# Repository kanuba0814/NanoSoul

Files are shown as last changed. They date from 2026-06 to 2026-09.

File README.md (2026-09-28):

# NanoSoul · ESP32-P4 桌面陪伴机器人

NanoSoul 是一台桌面陪伴机器人。它在本地检测人脸和环境，据此决定表情和动作；联网后可以进行语音对话。项目是团队参赛作品（2026 中国高校计算机大赛·人工智能创意赛），本仓库中的固件、测试上位机和文档由我提交。

当前实物是 **Waveshare ESP32-P4-WIFI6 开发板 + 现成模块 + 杜邦线**。

## 几个关键判断

- **实时决策不依赖云端。** 赛题要求主要功能运行在乐鑫芯片上，所以感知 → 决策 → 表情这条链全部在 ESP32-P4 本地完成：OV5647 → PPA 降采样 → ESP-DL 人脸检测 → 10 Hz、9 个状态的状态机。云端只负责深度对话，不进入决策环，因此断网时机器人照样能运转。
- **语音触发选能用的方案，而不是看起来高级的方案。** WakeNet9 和 MultiNet7 的模型加载和 AFE 管线都能跑，但在当前板载麦克风下口令检测不稳定。所以演示默认使用能量 VAD（检测到持续语音后才录音），再用 STT 文本判断是否包含唤醒词「小王」；神经网络方案保留为实验选项。
- **安全是硬需求，不是附加功能。** 电机堵转判定条件是 INA219 电流升高且编码器不动，触发后拉低 TB6612 的 STBY 急停；电机默认关闭，只有显式使能后才会驱动。
- **只有一块开发板，所以尽量把验证做在板外。** 共享脚本必须能在没有开发板的机器上运行；状态机、运动仲裁、堵转判定等逻辑都有板外自检（`soul_sim`、`arbiter`、`stall_sim` 等），上板后再用 SELFTEST 模式逐项确认。

## 验证状态

| 状态 | 内容 |
|---|---|
| ✅ 实物验证 | 本地人脸检测约 8 fps；480×640 屏幕动画表情约 30 fps；断网运行本地状态机；录音 → STT → LLM → TTS → 播放全链路（2026-07-08 打通，120 s 稳定性测试无 panic / WDT / reset）；WebSocket 上位机与测试模式 |
| 🟡 代码完成，只通过板外自检 | 三轮全向运动原语、堵转保护闭环、轮速闭环与里程计（校准记录尚未填写）；IMU、环境光组件需接线后实测 |
| ⬜ 未完成 | 外壳打印装配（目前只完成 SolidWorks 初步建模）、工具调用、OTA |

完整的功能清单和每一项的状态见 [`docs/00_成品全景与技术框架.md`](docs/00_成品全景与技术框架.md)。

## 开发方式

开发过程与 Claude Code 协作完成，约定写在 [`CLAUDE.md`](CLAUDE.md)：优先复用乐鑫官方组件，现成没有的由 AI 产出、人工复核；commit 前固件必须通过 `idf.py build`；AI 给出的接线、电平和上电顺序全部由人复核。

## 目录

```text
main/                 程序入口和板级驱动（电机、编码器、INA219）
components/           视觉、状态机（soul）、表情、运动、语音、联网、自检等组件
esp_emote_gen_player/ 乐鑫表情播放器（vendored）
spiffs_image/         表情资源包
sdcard_template/      SD 卡配置示例，不含真实密钥
tools/testhost/       浏览器测试上位机与诊断工具
enclosure/            SolidWorks 外壳源文件与导出
docs/                 系统说明、接口协议、引脚表和测试记录
```

## 编译与烧录

开发环境：ESP-IDF v5.5.2，目标芯片 ESP32-P4。

```bash
source $IDF_PATH/export.sh
idf.py set-target esp32p4
idf.py build
idf.py -p /dev/ttyACM0 flash monitor   # 需要连接开发板
```

SD 卡配置和上板自检见 [`docs/10_上板验证_SD配置与烧录.md`](docs/10_上板验证_SD配置与烧录.md)。复制 `sdcard_template/nanosoul/config.example.json` 到 SD 卡 `/nanosoul/config.json`，填写 Wi-Fi 和模型服务配置；真实密码和 API Key 不进仓库。

## 运行模式

- `FACE`：默认模式，运行表情、视觉、状态机、语音、联网和上位机服务。
- `SELFTEST`：循环运行整机自检，输出 JSON 结果。
- `TEST`：在完整运行时之上增加传感值注入、电机测试和串口协议；上电时 IO48 接地即可进入。浏览器上位机为 [`tools/testhost/index.html`](tools/testhost/index.html)，协议见 [`docs/13_测试模式与上位机_v1.md`](docs/13_测试模式与上位机_v1.md)。

## 硬件接线

开发板由 USB 供电，电池经 XL6009 升压后单独给电机供电，两路电源必须共地；电机干线走母排并星形接地，避免电机一转电机电源就被拉低到 1.3 V。引脚见 [`docs/BOARD_MAPPING.md`](docs/BOARD_MAPPING.md)，接线图见 [`docs/应急方案_无PCB/`](docs/应急方案_无PCB/)。

## 分支与标签

| 分支 / 标签 | 内容 |
|---|---|
| `main` | 当前整机固件 |
| `v1.0-submission` | 赛前提交时的验证版本 |
| `test` | 完整测试固件：全量组件、testhost 与工具链 |
| `test-host` | 测试上位机与公开版文档整理 |
| `soul-app` | 交互里程碑 M1–M8：自主行为、堵转保护、微动作 |
| `feat-p4-hw-baseline-from-testP4` | 从测试板迁移 P4 硬件基线的最早版本 |

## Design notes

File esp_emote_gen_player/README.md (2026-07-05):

# ESP Emote Gen Player

<p align="center">
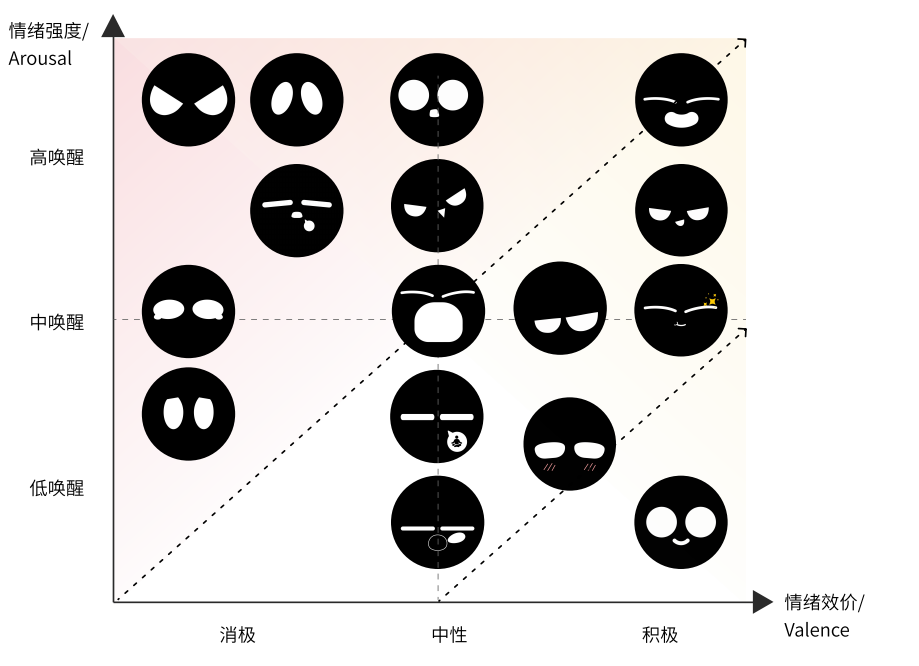
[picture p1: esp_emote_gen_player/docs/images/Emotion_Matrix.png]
情绪矩阵 — 效价 × 唤醒度与表情资产分类
  
</p>

**Emotion design specification · 表情设计规范**

The matrix above is the **current taxonomy** for mapping emotional states (valence × arousal) to emote asset categories. Authoring, naming, and export should follow the official guidelines in the PDFs below (Simplified Chinese).

上图情绪矩阵为当前 **效价 × 唤醒度** 与表情资产类别的对应关系；制作、命名与导出请遵循下列 PDF 规范。

| Document |
| -------- |
| [表情动效系统规范文档.pdf](https://dl.espressif.com/AE/%E8%A1%A8%E6%83%85%E5%8A%A8%E6%95%88%E7%B3%BB%E7%BB%9F%E8%A7%84%E8%8C%83%E6%96%87%E6%A1%A3.pdf) |
| [表情设计规范.pdf](https://dl.espressif.com/AE/%E8%A1%A8%E6%83%85%E8%AE%BE%E8%AE%A1%E8%A7%84%E8%8C%83.pdf) |

**Languages / 语言:** [中文](#中文) · [English](#english)

---

## 中文

在设备上挂载 **打包工具导出的二进制资源包**，驱动 **`gfx_anim`** 播放（片段规划、立即切换与当前片段播完后再交接）。

页面顶部的 **情绪矩阵** 与 **两份规范 PDF** 定义分类与制作约束；导出资源时请与之对齐。

### 打包工具（主机端）：ESP Emote GFX Packer NEXT

> 浏览器端编辑工程，**导出 `*.bin`** 后烧录到设备；与目标屏的 **分辨率 / 画布** 一致即可。

**[ESP Emote GFX Packer NEXT (dev)](https://emote-gfx-gen-tool-dev.pages.dev/)**

#### 1. 屏幕设置

配置目标 **宽 / 高**（像素）、必要时 **矩形**画布与 **背景色** 并应用，使其与实际运行的显示屏一致。

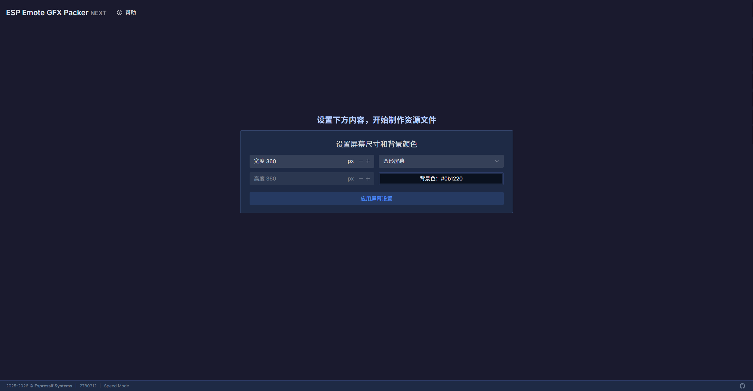
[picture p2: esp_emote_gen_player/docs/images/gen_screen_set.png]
ESP Emote GFX Packer NEXT — 分辨率与背景。


#### 2. 载入源动画

导入 **GIF**（或其它编辑器支持的来源）；按需调整时间轴与布局，细节见应用内 **Help**。

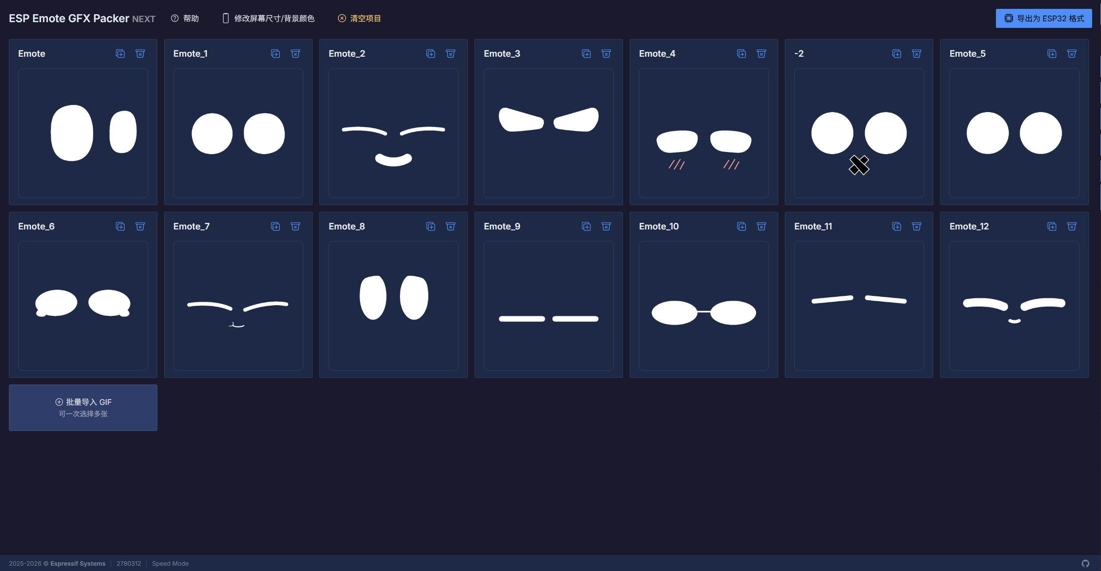
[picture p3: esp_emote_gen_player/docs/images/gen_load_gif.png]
ESP Emote GFX Packer NEXT — 将 GIF 载入工程。


#### 3. 导出

使用打包工具的 **导出 / 下载** 得到二进制；导出尺寸随编辑器中的 **屏幕设置**，源图层会 **自动缩放** 以适配画布。挂载后由 **本组件** 解析包内资源。

**`test_apps` 预编译示例包：** [`emote_assets.bin`](https://dl.espressif.com/AE/emote_assets.bin)

### 示例素材

> **GIF / Lottie** 等源文件合集，可导入上述打包工具再导出设备端包；由 **乐鑫 ESP 开源** 提供。

[**Emote Pack.zip**](https://dl.espressif.com/AE/Emote%20Pack.zip)

### 用法

将本仓库以本地路径加入工程依赖，初始化后挂载分区或路径上的资源包并切换动画：

```yaml
# idf_component.yml
dependencies:
  esp_emote_gen_player:
    path: ../path/to/esp_emote_gen_player
```

```c
#include "emote_gen_player.h"

emote_gen_player_handle_t player = emote_gen_player_init(&cfg);
// …

emote_gen_player_data_t data = {
    .type = EMOTE_GEN_PLAYER_SOURCE_PARTITION,
    .source.partition_label = "emote_gen",
    .flags.mmap_enable = 1,
};

ESP_ERROR_CHECK(emote_gen_player_mount_assets(player, &data));
ESP_ERROR_CHECK(emote_gen_player_anim_now_name(player, "idle"));
```

### 功能说明与测试

- 加载设备端由打包工具生成的 **二进制资源包**；挂载动画资源并接入 **`gfx_anim`** 的片段规划。
- **`emote_gen_player_init` / `deinit`**：gfx 运行时、单显示器、内部动画对象。
- **`emote_gen_player_mount_assets`**：从 **分区** 或 **文件系统路径** 加载资源包（可选 mmap）。
- **动画切换**
  - **`emote_gen_player_anim_now` / `_name`**：立即切到目标片段。
  - **`emote_gen_player_anim_fade` / `_name`**：先让当前片段规划播完（`gfx_anim_play_left_to_tail`），再切换 — **请勿在持有渲染锁的 gfx 触摸定时器回调里直接调用**；应放到其它任务中延迟执行（见 `test_apps`）。
- **本仓库 `test_apps/`**：独立 `idf.py` 工程（板级初始化、触摸安全的动画切换）。详见 **`test_apps/README.md`**。

---

## English

On device, **mounts packer-produced binary emote packs** and drives **`gfx_anim`** (segment plans, immediate switch vs. handoff after the current plan).

The **emotion matrix** and **two specification PDFs** at the top define taxonomy and authoring rules (Simplified Chinese); align exports with them.

### Pack tool (host): ESP Emote GFX Packer NEXT

> Author in the browser, **export `*.bin`**, then flash. Match the editor **canvas / resolution** to your target display.

**[ESP Emote GFX Packer NEXT (dev)](https://emote-gfx-gen-tool-dev.pages.dev/)**

#### 1. Screen setup

Configure **width / height** (px), optional **rectangular** canvas, and **background color**, then apply.

ESP Emote GFX Packer NEXT — screen size and background.

#### 2. Load source animation

Import **GIF** (or other supported sources). Adjust timing and layout; see in-app **Help** for details.

ESP Emote GFX Packer NEXT — load GIF into the project.

#### 3. Export

Use **Export / Download** to produce the binary. Export follows the **screen size** in the editor; layers are **rescaled** to fit. **This component** parses the mounted pack.

**Prebuilt sample for `test_apps`:** [`emote_assets.bin`](https://dl.espressif.com/AE/emote_assets.bin)

### Sample sources

> **GIF / Lottie** sources bundled for import into the packer above; **ESP open-source** from Espressif.

[**Emote Pack.zip**](https://dl.espressif.com/AE/Emote%20Pack.zip)

### Usage

Add this component via `idf_component.yml`, then mount a partition or filesystem path and switch clips:

```yaml
# idf_component.yml
dependencies:
  esp_emote_gen_player:
    path: ../path/to/esp_emote_gen_player
```

```c
#include "emote_gen_player.h"

emote_gen_player_handle_t player = emote_gen_player_init(&cfg);
// …

emote_gen_player_data_t data = {
    .type = EMOTE_GEN_PLAYER_SOURCE_PARTITION,
    .source.partition_label = "emote_gen",
    .flags.mmap_enable = 1,
};

ESP_ERROR_CHECK(emote_gen_player_mount_assets(player, &data));
ESP_ERROR_CHECK(emote_gen_player_anim_now_name(player, "idle"));
```

### What it does and tests

- Loads the packer-produced **binary asset pack**; wires **`gfx_anim`** segment plans.
- **`emote_gen_player_init` / `deinit`**: gfx runtime, one display, internal animation object.
- **`emote_gen_player_mount_assets`**: **partition** or **filesystem path** (optional mmap).
- **Animation switching**
  - **`emote_gen_player_anim_now` / `_name`**: cut to the target clip immediately.
  - **`emote_gen_player_anim_fade` / `_name`**: drain the current plan (`gfx_anim_play_left_to_tail`), then switch — **do not call from the gfx touch timer while the render lock is held**; defer to another task (see `test_apps`).
- **This repo — `test_apps/`**: standalone `idf.py` project. See **`test_apps/README.md`**.

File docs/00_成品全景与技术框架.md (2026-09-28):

# NanoSoul 成品全景与技术框架

> 本文汇总当前样机的功能、系统组成、实测结果和待完成事项，各专项以对应文档为准。
> 状态更新：**2026-07-26**。正式提交基线为 `v1.0-submission`；当前 `main` 另含 VAD 语音触发调整。

---

## 1. 最终成品定义

### 1.1 一句话定位（引自宪法 01）

> NanoSoul 是一台基于 ESP32-P4 的桌面陪伴机器人。它在本地检测人脸和环境状态，据此调整表情与运动；联网后通过云端服务完成语音识别、对话和语音合成。

赛题要求主要功能代码运行在乐鑫芯片上。NanoSoul 的视觉处理、状态判断和运动控制都在 ESP32-P4 上运行，云端服务不参与实时运动判断。断网演示用于验证这条本地处理链路。

### 1.2 成品功能全清单（含当前状态）

状态图例：✅ 已上板实测 · 🟡 已实现、待实测/待配置 · 📐 设计就绪、未实现 · ⬜ 待做

| 域 | 功能 | 技术落点 | 状态 |
|---|---|---|---|
| **感知** | 人脸检测（存在/位置/大小/正脸分） | OV5647 MIPI-CSI → PPA 降采样 300×480 → ESP-DL `HumanFaceDetect`（MSRMNP s8），实测 **8fps** | ✅ |
| | 距离代理 + 凝视判定 | bbox `area_ratio` 当距离、鼻眼关键点算 `frontal_score` | ✅ |
| | 碰撞 / 被抬起 / 倾斜 | QMI8658 软件检测（`components/imu`：敲击/双击/抬起/放下/倾斜），抬起→SOUL_LIFTED 反射停轮 | 🟡 组件就绪，待接线实测（imu_probe 自检） |
| | 环境光（暗光→睡觉） | BH1750 @I²C1 0x23（`components/light`，滞回→DARK/BRIGHT→SOUL_DOZE） | 🟡 组件就绪，待接线实测（light_read 自检） |
| | 电机电流（堵转判定输入） | INA219 @I²C1 0x40（`drv_ina219` 已有，TESTPANEL 已读通） | 🟡 |
| | 主人电脑状态（第二路在场/注意力源） | 上位机 `pc_state` 上报（09 v1.1）→ soul 注意力融合（12 §3.5，专注勿扰/挂机邀玩/锁屏预期） | 🟡（设备消费端已实现 fusion_sim 自检；采集端 PC 状态上报待做） |
| **决策** | soul 状态机（9 态，10Hz，全本地） | `components/soul`：IDLE/ENGAGE/APPROACH/RETREAT/GAZED/LISTEN/THINK/SPEAK/FAULT | ✅（`soul_sim` 自检 PASS） |
| | 主动陪伴行为：远了靠近、近了退后、朝脸转向、被盯久了害羞退避 | `soul_eval()`：area 阈值 + `wz=-0.8·cx` 居中 + gaze_hold 触发 GAZED | ✅ 逻辑实测，待接轮整机场测 |
| | 断网降级 | 感知→决策→表情/运动全链不依赖云 | ✅（bring-up 即断网跑通） |
| | 电机堵转急停（硬需求） | 电流高 + 编码器不动 → `motors_enable(false)` + FAULT，3 次试探恢复（`app_sense` stall FSM） | 🟡 闭环代码就绪（stall_sim 自检），待接轮实测 |
| **表达** | 动画表情脸（5 情绪：o/sad/sleep/think/waiting） | `esp_emote_gen_player`，640×480@30fps，90° 旋转刷 ST7701（480×640 竖屏） | ✅ |
| | 情绪↔状态映射 + 覆盖接口 | soul `apply_emotion()` / `soul_emotion_override()` | ✅ |
| | 对话字幕条（tip） | `face_set_tip()` | ✅ |
| | debug HUD（6 行遥测叠层，~2Hz） | `components/hud`，钉在 emote 画布上 | ✅ |
| | happy 表情 | 素材待做（07 P3） | ⬜ |
| **运动** | 三轮全向逆运动学（vx,vy,wz→三轮 duty） | `motion_ik()`，轮角 0°/120°/240°，饱和归一保航向 | ✅（`motion_ik` 自检 PASS） |
| | 实际驱动轮子 + 运动原语 | `motion.enabled` 默认 false 只算不驱动；意图仲裁器（6 源租约）+ 原语库（nudge/scan/spin/wiggle…）已实现 | 🟡 代码就绪（arbiter/prim_sim 自检），待接线（M1 IN 占 IO24/25 需挪脚） |
| | 编码器测速/里程 | PCNT ×4 解码，`ENC_COUNTS_PER_REV=28`（电机轴口径） | 🟡（TESTPANEL 自检固件实测过） |
| **语音对话** | 语音触发 | 默认能量 VAD：检测到持续语音后录音，再由 STT 文本门确认是否包含“小王”；MultiNet/WakeNet 保留为实验选项 | ✅ VAD 展示链与 120s 稳定性已验证；两套神经网络口令检测在当前条件下尚未稳定（2026-07-24） |
| | 录音→STT→LLM→TTS→播放 | `voice_task`：≤8s 录音尾静裁剪 → **seed-asr-2.0 单流 WSS 直连**（`volc_asr.c`）→ plan chat → seed-tts-2.0 HTTP → ES8311 播放；**全双工**（`WORK_MODE_BOTH`），播放期不读麦防回授 | ✅ **2026-07-08 实板全链打通**（说话→识别→回答→出声） |
| | 云端深度对话（三协议） | `llm_chat()`：Anthropic / OpenAI / **volc**（Agent Plan 端点 `/api/plan/v3` 或按量 `/api/v3`），SD 卡配 key；PC 侧 `tools/testhost/talk_probe.py` 可全链调参 | ✅ plan chat 实板已通 |
| | 文字问答（免语音） | 上位机 `ask` 命令 → `dialog_ask()` → 回复上字幕条 | 🟡 |
| **联网** | C6 WiFi6（esp_hosted/SDIO）、SNTP、mDNS `nanosoul.local` | `components/netlink` | 🟡（待 SD 配置实测） |
| **上位机** | WebSocket 接口：1Hz 全量 state + 即时 event + JPEG 快照 + 9 条命令 | `components/companion`，`ws://nanosoul.local/ws?token=…`，LAN only，协议冻结于 09 | ✅（`ws_loopback` PASS） |
| **供电保护** | 双电源共地（USB 逻辑 + 电池升压电机）、地母排星接 | 无 PCB 版实物方案（应急方案文档） | ✅ 实物验证 |
| **机械外壳** | 史莱姆形外壳（Ø160×h93，前脸 20° 后仰嵌屏，三全向轮 120° 布置一后两前） | `enclosure/`（SolidWorks 2024 手绘 + STL/3mf 导出） | 📐 初步建模，未打印装配 |
| **工具调用** | 本地工具（运动/表情/传感）+ 局域网 Home Assistant REST | 宪法 §4.5 混合方案 | ⬜ |

---

## 2. 系统技术框架

### 2.1 总框图

```
                         ┌─────────────── 云端（仅深度对话，不进决策环）───────────────┐
                         │  chat: Anthropic /v1/messages ←→ OpenAI /v1/chat/completions │
                         │  STT: /v1/audio/transcriptions   TTS: /v1/audio/speech       │
                         └────────────────────────△─────────────────────────────────────┘
                                                  │ HTTPS (esp_crt_bundle)
┌── 上位机 (PC/LAN) ──┐                ┌──────────┴──────────────  ESP32-P4 ─────────────────┐
│  WS 客户端           │◄── ws://…/ws ──┤ companion │ llm │ netlink ── C6 WiFi6 (esp_hosted)   │
│  state/event/snapshot│                │           │     │                                    │
└─────────────────────┘                │  ┌────────┴─────┴──────────────────────────┐        │
                                       │  │        telemetry（快照 + 事件总线）        │        │
                                       │  └──△───────△────────△───────△─────────△───┘        │
   OV5647 ─ MIPI-CSI ─ camera ─► vision ──►│ soul ──►│ motion ─► TB6612×2 ─► 3×N20+全向轮      │
   （800×1280）  (PPA→300×480)  (ESP-DL 8fps)│ 10Hz    │  IK      （PCNT 编码器×3 回采）         │
                                       │    └──────►│ face ──► emote player ─► ST7701 480×640 │
   ES8311 麦/喇叭 ◄── audio ◄── voice ──┘  (表情+tip+HUD)         (640×480@30fps, 90°旋转)     │
   SD 卡(config.json) ── storage_sd     QMI8658/BH1750/INA219 @I²C1（传感三件套，接入中）       │
└──────────────────────────────────────────────────────────────────────────────────────────┘
```

### 2.2 硬件：当前实物

固件对着无 PCB 模块版编写，接线真值见 CLAUDE.md 固件节与 BOARD_MAPPING.md。

| 载体 | 状态 | 要点 |
|---|---|---|
| **无 PCB 杜邦版** | ✅ 在用 | 现成模块 + 杜邦线；双电源（电脑 USB 供开发板、1S 电池→XL6009 升 5.9V 只带电机）**必须共地**；红/蓝母排干线 + 星地（锚点 XL6009 OUT−），防「电机一转 VM 塌到 1.3V」复发。细节见 `docs/应急方案_无PCB/` |

### 2.3 计算平台与板载资源

Waveshare **ESP32-P4-WIFI6**（v1.3 硅版实测）：16MB flash（QIO）/ 32MB PSRAM（200MHz，XIP）/ ESP32-C6 协处理（WiFi6，SDIO esp_hosted）。板载外设（引脚宏见 `components/bsp/bsp_pins.h`）：

- **屏**：ST7701S 480×640 竖屏，MIPI-DSI 1-lane@700Mbps。
- **相机**：OV5647，MIPI-CSI，SCCB@I²C0 0x36。⚠️ CSI 与 DSI 共用 MIPI DPHY 电源轨，靠 `cmake/patch_esp_video_ldo.cmake` 把 esp_video 补丁到 **LDO_VO3@2500mV**，否则相机不上电。
- **音频**：ES8311 codec（I²C0 0x18，I2S0）+ NS4150B 功放（PA_EN=IO53），16kHz/16bit/mono 全双工。
- **SD**：**SDSPI 模式**（CLK=IO43/MOSI=IO44/MISO=IO39/CS=IO42），LDO_VO4 供 IO 轨。
- **I²C0**（IO7/IO8）：板载三客户（codec/触摸/相机 SCCB），`board_i2c0` 组件统一建总线；**I²C1**（IO20/IO21，100kHz）：外接传感三件套。

### 2.4 固件架构（18 组件 + main）

ESP-IDF v5.5.2，`idf.py set-target esp32p4`。分层：

| 层 | 组件 | 职责一句话 |
|---|---|---|
| 地基 | `telemetry` | 全局遥测快照（mutex 保护）+ esp_event 事件总线，所有组件的汇聚点 |
| | `storage_sd` | SDSPI 挂卡 + `/sdcard/nanosoul/config.json` 字段级 overlay 配置（缺卡用内建默认） |
| | `bsp` / `board_i2c0` | 板载固定引脚宏 / I²C0 总线单例 |
| | `selftest` | 自检注册表 + 循环跑批，每项一行 JSON 到串口（19 项，见 §4） |
| 感知 | `camera` | esp_video(V4L2) 采 800×1280 RGB565 → PPA 全 FOV 降采样 300×480 → 帧回调；硬件 JPEG 快照 |
| | `vision` | ESP-DL 人脸检测（C++），产出 `tel_face_t{present,cx,cy,area_ratio,frontal_score}` |
| 决策 | `soul` | 10Hz 状态机：人脸观测 + 外部刺激（语音会话/故障）→ motion intent + face 情绪 |
| 表达 | `face` | emote 播放器薄封装：点屏、90° 旋转 flush、挂 `emote_gen` 分区、切换队列 |
| | `hud` | 遥测 6 行叠层（SOUL/FACE/MOT/ENC/NET/FPS），让没接的外设参数也可见 |
| 运动 | `motion` | 全向 IK + 输出闸：disabled 只算 + 发遥测；enabled 才经回调驱 `drv_motor` |
| 语音 | `audio` / `voice` | ES8311 录放 / wake→录音→STT→chat→TTS→播 全流水线（半双工） |
| 云 | `llm` / `dialog` | 双协议 chat + STT/TTS 客户端 / 单轮对话编排（voice 与上位机 ask 共用） |
| 网络 | `netlink` / `companion` | C6 WiFi + SNTP + mDNS / WS 服务（state/event/命令，token 鉴权） |
| 板级驱动 | `main/drv_motor·drv_encoder·drv_ina219` | TB6612（LEDC 20kHz）/ PCNT 正交 / INA219——无 PCB 外接件，TESTPANEL 实例化 |

（`display` 组件只服务 legacy TESTPANEL 的 LVGL 面板；FACE 模式的脸走 emote gfx 链，**不经 LVGL**。`esp_emote_gen_player/` 是 vendored 乐鑫官方播放器，`face` 是它的薄执行层。）

**三种启动模式**（编译期 Kconfig `NANOSOUL_MODE` 单选）：

- **FACE**（默认，产品/演示）：完整运行时——脸+HUD+视觉+soul+motion+网络+云+语音+companion。
- **SELFTEST**（首次上板/烤机）：同一套运行时 + 每 5s 一轮 19 项自检循环。
- **TESTPANEL**（legacy）：LVGL 三电机点检面板，与整机解耦。

**任务与核分配**：

| 任务 | 组件 | 核 | 优先级 | 周期 |
|---|---|---|---|---|
| gfx 渲染（emote 内部） | face | 1 | 7 | 30fps |
| `stream_task` 相机采集 | camera | 1 | 5 | V4L2 循环 |
| `detect_task` 人脸推理 | vision | 0 | 4 | 尽力（实测 8fps） |
| `soul_task` 决策 | soul | 0 | 5 | 10Hz |
| `voice_task` 语音会话 | voice | 0 | 5 | 事件驱动 |
| `switch_worker` 表情切换 | face | 0 | 6 | 队列 |
| `dialog_task` | dialog | 0 | 4 | 队列(4) |
| `hud_task` | hud | 0 | 4 | 500ms |
| `push_task` WS 心跳 | companion | 0 | 3 | 1Hz |

### 2.5 云端与上位机

- **chat 双协议**（`chat.provider` 选）：Anthropic（`x-api-key` + `anthropic-version: 2023-06-01`，system 顶层字段）或 OpenAI 兼容（Bearer，system 进 messages[0]）。非流式短回复，`max_tokens` 默认 512，TLS 用内置证书 bundle，超时 20s。
- **STT/TTS**：OpenAI 兼容 `/v1/audio/transcriptions`（multipart WAV）与 `/v1/audio/speech`（收 WAV→最近邻重采样到 16kHz）。三套端点可指不同 provider，各配各的 key。
- **上位机 WS**（协议冻结 = 09）：`state` 1Hz 全量 / `event` 即时（soul_transition·face_present/lost·gazed·wake·llm_reply·fault·selftest_item）/ binary JPEG 快照；命令 `ask·set_emotion·teleop·get_snapshot·estop·clear_fault·config_reload·set_overlay·selftest`，一律回 `ack{id,ok,err}`。未知 type 必须忽略（前向兼容铁律）。

---

## 3. 技术配合：数据流与契约

### 3.1 本地感知→决策→输出链路（断网可用）

```
OV5647 → camera(core1) —PPA 300×480→ vision(core0, ESP-DL) → tel_face_t
    → soul_task 10Hz: soul_eval()
        ├─ motion_set_intent(vx,vy,wz) → IK → duty[3] → 遥测（enabled 时才驱 TB6612）
        ├─ apply_emotion() → face_set_emotion() → emote 播放器 → 屏
        └─ telemetry_set_soul() + SOUL_TRANSITION 事件
    → hud 2Hz / companion 1Hz 从同一遥测快照对外可视化
```

决策优先级（`soul_eval`）：FAULT > 语音会话（LISTEN/THINK/SPEAK，不动）> GAZED 回避（vx=−0.5，1.5s 窗）> 无脸 IDLE（可选 idle_scan）> 有脸按 `area_ratio` 分档：>near_hi→RETREAT、<near_lo→APPROACH、之间→ENGAGE；ENGAGE 里 `frontal>0.7` 累计 ≥`gaze_hold_ms`→GAZED。所有有脸态叠加 `wz=−0.8·cx` 朝脸转向。阈值全部走 SD 配置 `behavior{}`，可现场调。

### 3.2 语音会话流水线（全双工硬件，会话半双工时序）

能量 VAD 唤醒（1s 预卷环把触发词并入录音；或上位机 `voice_trigger`）→ `soul_notify_wake()`（LISTEN + tip「(听)」）→ 录音 ≤8s/尾静 800ms（静音阈 rms&lt;350）→ THINK → seed-asr WSS（空文本=误唤醒，**静默丢弃**不打扰）→ chat → 回复上字幕条 + `LLM_REPLY` 事件 → SPEAK → TTS → 播放（PA 拉高，期间不读麦防回授）→ 回感知闭环。失败路径有声（fail tone 两下行音）+ tip 文案；断网不发请求直接兜底。

### 3.3 事件总线与遥测快照

单一事实源两条路：**连续量**走 `tel_snapshot_t` 快照（生产者 setter 写 / 消费者 `telemetry_get()` 原子读）；**离散事件**走 esp_event（`ns_event_id_t`）。事件当前唯一订阅者是 `companion`（转 WS `event` 帧）：

| 事件 | 发布者 | 含义 |
|---|---|---|
| `NS_EVT_SOUL_TRANSITION` / `NS_EVT_GAZED` | soul | 状态跳变 / 凝视触发 |
| `NS_EVT_FACE_PRESENT` / `NS_EVT_FACE_LOST` | vision | 人脸出现/消失边沿 |
| `NS_EVT_WAKE` / `NS_EVT_FAULT` | soul（voice/外部触发） | 唤醒 / 故障（含 estop） |
| `NS_EVT_LLM_REPLY` | voice / dialog | 云回复文本（≤160B） |
| `NS_EVT_SELFTEST_ITEM` | selftest | 单项自检结果 |

### 3.4 配置系统（密钥纪律）

`/sdcard/nanosoul/config.json`（模板 `sdcard_template/`，**真实密钥只在卡上、永不进仓库**），字段级 overlay 内建默认、缺卡可跑：
`wifi{ssid,password}` · `chat{provider,base_url,api_key,model,max_tokens,system_prompt}` · `stt{…}` · `tts{…,voice}` · `behavior{near_lo=0.04,near_hi=0.18,frontal_thresh=0.70,gaze_hold_ms=1500,idle_scan}` · `motion{enabled=false,max_duty_pct=40}` · `companion{enabled=true,token}` · `debug{overlay=true,log_level}`。上位机 `config_reload` 命令可热重载。

### 3.5 存储布局与资源管线

16MB flash，A/B 双 OTA（`partitions.csv`）：`ota_0/ota_1` 各 5MB · `emote_gen` 1.5MB（表情包）· `human_face_det` 1MB（人脸模型，label 名是组件硬性要求）· `model` 3MB（ESP-SR 语音模型：mn7_cn + wn9_nihaomiaoban_tts2，label 名是 esp-sr CMake 自动烧录的硬性要求）· `storage` FAT。
表情资产：`spiffs_image/*.bin`（5 情绪各一包，共 ~991KB）—构建时 `tools/emote_repack.py` 合成 `nanosoul_emote.bin` 随 `idf.py flash` 烧入 `emote_gen`，运行时 mmap 挂载。

### 3.6 内存纪律（bring-up 实证）

`SPIRAM_MALLOC_ALWAYSINTERNAL=4096`：≥4KB 分配走 PSRAM（emote 绘制缓冲、语音 utterance、TTS 累积均在 PSRAM），保住 256KB 内部 SRAM；esp_hosted mempool 也必须进 PSRAM（`ESP_HOSTED_MEMPOOL_PREFER_SPIRAM=y`），否则开机断言循环。PPA 输出缓冲按 cache line（128B）对齐，否则丢帧。

---

## 4. 实测基线（2026-07-05 上板 bring-up，v1.3 硅版）

自检矩阵（SELFTEST 模式，19 项）：**13 PASS · 4 SKIP · 1 FAIL**

- ✅ PASS 含全部核心链路：`sd_mount/config_parse/psram/partition_layout`、`emote_mount/emote_render/hud_draw`、`i2c0_probe/camera_stream/face_detect`、`motion_ik/soul_sim`、`codec_playback`、`ws_loopback`。
- ⏭ SKIP ×4：`wifi_connect/sntp/llm_ping`（SD 未配 WiFi/key）+ `wakenet_load`（MANUAL，本版能量 VAD）。
- ❌ FAIL ×1：`mic_record`——ES8311 ADC 静音（录音路径此前标注为板上未验证项）。**→ 已于 2026-07-08 语音链上板收尾打通（`ec3af47`）：mic 录音正常、说话→seed-asr→云 LLM→seed-tts→出声全链实测、对话可演示；此 07-05 FAIL 已消解，自检计数待重跑刷新。**

关键实测数字：相机 800×1280 采集 → 人脸检测 **8fps**；emote 渲染 640×480@**30fps**；断网状态本地闭环（看到人→表情/意图响应）完整跑通。bring-up 踩坑与修复（hosted mempool、LDO、PPA 对齐、HUD mask_buf 等）已固化进 `sdkconfig.defaults` 与代码，复现细节见 10 篇附录与 commit `baf909d`。

---

## 5. 差距清单：从成品倒推

### A. 固件收尾（对着现有无 PCB 硬件就能做）

> 交互行为的完整设计（场景库/情绪引擎/运动原语/仲裁架构）= **12 篇**。**I0–I2 已全部代码落地并板外 build 通过**（8 个里程碑 commit，纯逻辑自检 6 项恒绿：arbiter/expr/fusion/imu/prim/stall_sim；SELFTEST 自检项从 19 增至 28）。以下为剩余：

1. ~~**修 `mic_record` FAIL**（ES8311 ADC 静音）——语音链路唯一断点，最高优先。~~ **已解（2026-07-08 `ec3af47`）**：mic 录音打通，说话→seed-asr→云 LLM→seed-tts→播放全链上板实测、对话可演示。
2. ~~交互 I0+I1~~ **已落地（待上板实测）**：motion 意图仲裁器（已修 teleop 被 soul 覆写）、表情规则引擎、短期记忆、PC 状态融合；传感三件套组件就绪（QMI8658 敲击/抬起/倾斜、BH1750 暗光→DOZE、FT6x36 触摸单读者）——接线后 SELFTEST 的 `imu_probe/light_read/touch_probe` 应转 PASS。
3. ~~接轮 I2~~ **代码就绪（待接轮真机验证，由 Captain 执行）**：运动原语库、自主行为（零位移约束）、微动作、**堵转过流保护闭环**均已实现且 build 通过；上板前先挪 M1 IN1/IN2 出 IO24/25（USB-JTAG 冲突）→ SD 配 `motion.enabled=true`。
4. **语音触发后续工作（2026-07-24）**：当前默认使用能量 VAD（RMS>220 持续 160ms）启动录音，再由 STT 文本门确认“小王”。提示音、STT→LLM→TTS 和续聊已完成实物测试，120s 内未出现 panic、WDT 或 reset。MultiNet7-cn 和 WakeNet9 的模型加载及 AFE 管线可以运行，但口令检测在当前板载麦克风和模型配置下尚未达到稳定展示要求，因此保留为实验选项。
5. happy/blink 表情素材 + PPA 硬旋转优化（07 P3、12 I3）；IMU 片上事件引擎（当前软件检测，P1）。

### B. 硬件落地

1. **外壳**：SolidWorks 初步建模已完成，尚未打印装配；电池方案待统一（当前无 PCB 版为 1S 软包）。

### C. 比赛交付

1. 断网演示脚本 + 现场 fallback。
2. 上位机 PC 客户端：WS 协议真值见 09（已冻结、companion 已实现）；含 **PC 状态采集上报**（机器人的第二路感知，09 v1.1 `pc_state`）。
3. 工具调用（本地工具 + HA REST demo）、OTA、报名材料（宪法 §4.5）。

---

## 6. 文档地图与阅读顺序

| 篇 | 定位 | 状态 |
|---|---|---|
| **00（本文）** | 成品全景 + 技术框架 + 差距，docs 入口 | 2026-07-05 基线 |
| 01 项目宪法 | 不可动摇的核心决策：赛题、定位、原则、反面清单、答辩话术 | 有效（§4.2 已按去悬崖/QMI8658 修订） |
| 02 硬件规格附录：驱动可用性 | 外设官方驱动/组件可用性 | 有效 |
| 06 IMU 选型查证 | QMI8658 顶替 ICM-42688-P 的证据链 + 下单料号（QMI8658A） | 当前 IMU 真值 |
| 07 表情子系统 | emote 播放器接入的执行计划 | **已执行完毕**（P0–P2 落地，P3 开放） |
| 08 整机程序总体计划 | Phase 0–F 的架构与验收计划 | **已全部执行完毕**；as-built 架构见本文 §2–§3 |
| 09 上位机接口协议 v1 | WS 协议真值（冻结） | 已实现（companion），与实现一致 |
| 10 上板验证 | 持板者操作手册：SD 配置、烧录、读自检 | 有效；含 bring-up 实测记录 |
| 12 整机交互设计 | 行为真值源：智能感七原则、15 场景库、情绪引擎、运动原语、意图仲裁、I0–I3 分期 | v1，2026-07-05（设计态，待落地） |
| BOARD_MAPPING | 引脚真值源（模块版） | 有效 |
| 应急方案_无PCB/ | 当前实物接线真值（母排/星地/双电源） | 有效，与固件一致 |

**阅读顺序建议**：新读者 00 → 01 → 10（想上手跑）或 00 → BOARD_MAPPING（想动硬件）或 00 §2–§3 → 代码（想动固件）。

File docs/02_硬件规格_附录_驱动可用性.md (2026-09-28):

# 02 硬件规格 附录：外设官方驱动/组件可用性

> 本附录追加到《02_硬件规格_P0.3》。**硬件选型本身不变**（已确认），本附录只标注每个外设"是否有乐鑫官方现成驱动/组件可直接用"。

## 1. 外设驱动可用性映射

| 外设 | 接口 | 官方现成件 | 状态 | 固件策略 |
|---|---|---|---|---|
| OV5647 摄像头 | MIPI-CSI | **esp_video + esp_cam_sensor**（自动检测 OV5647，自带 ISP） | ✓ 官方 | 改配置即用；CSI 供电需 LDO 2500mV |
| MIPI-DSI 屏 | MIPI-DSI | **esp_lvgl_port**（`lvgl_port_add_disp_dsi`，P4 PPA） | ✓ 官方 | 直接用；PPA 实验性，留软渲染回退 |
| BH1750 环境光 | I²C1 | **`espressif/bh1750`** 组件 | ✓ 官方 | 直接用 |
| 磁编码器 | GPIO/PCNT | **PCNT `rotary_encoder`** 示例 | ✓ 官方 | 移植，三路 PCNT 正交解码 |
| N20 电机 | PWM | **MCPWM `mcpwm_bdc_speed_control`**（带 PID） | ✓ 官方 | 单电机示例 → 改写三电机 |
| TB6612FNG | GPIO+PWM | 无需专用驱动 | — | LEDC/MCPWM + 方向 GPIO |
| INMP441 / 板载麦 | I²S | **ESP-SR AFE**（采集 + AEC/VAD） | ✓ 官方 | feed/fetch 流水线对接 |
| ES8311 codec | I²S | **esp_codec_dev** | ✓ 官方 | 直接用 |
| ESP32-C6（WiFi6） | SDIO | **esp_hosted**（板载已预刷） | ✓ 官方 | 按文档配；配网两芯手动适配 |
| **QMI8658 IMU**（已换型，原 ICM-42688-P 方案废） | SPI / I²C | **SensorLib**（社区最全，含片上 Tap/WoM 事件引擎）、`waveshare/qmi8658`（官方 registry，原始数据） | ✓ 现成 | 直接用（选型证据链见 06）；换型原因之一 = ICM-42688 无官方 SPI 驱动 |
| ~~ITR20001 悬崖~~ | — | — | **已砍**（本版无悬崖） | 本版无悬崖传感器，IMU 兜底 lift/碰撞 |
| MT3608 / DW01+8205A / SS34 | 模拟电源 | — | — | 纯硬件，无固件 |

**小结（随 QMI8658 换型与去悬崖更新）**：外设几乎全部有现成件——IMU 换 QMI8658 后用 SensorLib/官方 registry 组件，悬崖已砍；不需要自写底层驱动。

## 2. 采购与硅版注意（更新）

- **优先采购 ESP32-P4 v3.x 硅版**：v3.x 修复了 ISP/MSPI 等若干问题（如 MSPI 上电唤醒 Load access fault、secure boot 校验异常），规避 MIPI-CSI 调试坑。
- **ESP-IDF 用 v5.4 / v5.5 稳定分支**（开发前回乐鑫赛题指引确认推荐版本）。
- **CSI 调试**：若 OV5647 偶发崩溃（如 0x102），开 `CONFIG_CAM_CTLR_MIPI_CSI_ISR_CACHE_SAFE` 等 IRAM 安全选项。
- ~~待确认项 Q1/Q2/Q3~~ **已解**（2026-07-05）：板 = Waveshare ESP32-P4-WIFI6，实到货 **v1.3 硅版**且整机 bring-up 已通过（docs/10 §6，CSI 靠 `ISR_CACHE_SAFE` + LDO_VO3@2500mV 补丁稳定）；板载麦经 ES8311（录音路径 `mic_record` 自检 FAIL 待查）。

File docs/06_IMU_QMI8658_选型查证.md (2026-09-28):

# 06 IMU 选型查证：QMI8658(C) 顶替 ICM-42688-P

> 背景：原计划 ICM-42688-P，实际到货是 **QMI8658**（紫色 GY 模块，丝印 QMI8658A / QMI8658C，引脚 VCC/GND/SCL/SDA/XDA/XCL/ADO/INT）。本文是对它能否替代的查证记录，供大家下单/接线前对一遍。
>
> 真值源说明：引脚分配以 [`BOARD_MAPPING.md`](BOARD_MAPPING.md) 为准；规格以 **QST 官方 QMI8658C Datasheet Rev A（文档号 13-52-27，2022-06-20）** 为准。本文不复述 datasheet 全文，只摘对决策有用的部分。

## 选型结论

> **下单(JLC SMT)注意（2026-06-30）**：嘉立创 SMT 库里 **QMI8658C(`C2842151`) 已停产/邮寄**，下单改同族 **QMI8658A(`C3021082`，现货 39k、可自动贴装)**。同 LGA-14、**脚位与 4 线 SPI 接法完全一致**（A 版 datasheet 13-52-25 Table 3 + Fig.4「4-Wire SPI」核过：1=SDO 4=INT1 5=VDDIO 6/7=GND 8=VDD 12=CS 13=SCL/SPC 14=SDA/SDI，2/3/9/10/11 SPI 下可悬空）、驱动同（SensorLib/Waveshare 同支持 A/C）→ **板与固件不动，仅 BOM 料号换**。本文余下规格按 C 版写，A 版同族同适用。

**QMI8658C 可以替代 ICM-42688-P 用在 ESP32-P4 上做本项目的 IMU**。它是 6 轴、支持 SPI 与 I²C、3.3V 可直供、有 INT1/INT2 两路中断，且**片上自带 Tap / Any-Motion / Wake-on-Motion 事件引擎**，碰撞、抬起、被搬动这几个事件可直接出中断，不必全靠固件算原始数据。

- **碰撞检测** → 片上 Tap（敲击）引擎，或 Any-Motion。
- **抬起 / 被搬动** → Any-Motion / Wake-on-Motion 引擎出中断。
- **电机堵转振动辅助** → 没有专用引擎（ICM 也没有），固件读高 ODR 原始数据做能量/FFT 阈值。这条两颗芯片一样，不影响选型。

代价：噪声比 ICM-42688-P 高（陀螺约 5 倍、加速度约 2 倍），陀螺量程上限只有 ±1024 dps，6 轴最大 ODR 7.17 kHz（ICM 是 32 kHz）。**这些差距对"撞了没 / 抬了没 / 振动超阈没"这种事件判定毫无影响**——我们不做姿态积分导航，用不上 ICM 的低噪声。结合驱动生态（见下），QMI8658 在本用途上反而更省事。

> 这一条同时更新了 [`02_硬件规格_附录_驱动可用性.md`](02_硬件规格_附录_驱动可用性.md) 第 18 行对 IMU 的判断：IMU 这项从「无官方驱动、需自研」改善为「有 Espressif 官方 registry 组件 + 成熟社区库」。

## 关键规格表

| 项目 | QMI8658C | ICM-42688-P | 出处 |
|---|---|---|---|
| 轴数 | 3 加速度 + 3 陀螺（6 轴，各 16-bit） | 同 | DS §1.3 Fig.2 |
| 加速度量程 | ±2 / ±4 / ±8 / ±16 g | 同 | DS Table 7 |
| 陀螺量程 | ±16 … **±1024 dps**（上限 1024） | ±2000 dps | DS Table 8 |
| 加速度最大 ODR | 仅加速度 1000 Hz；6DOF **7174.4 Hz** | 32 kHz | DS Table 9 |
| 陀螺最大 ODR | 6DOF **7174.4 Hz**（同步陀螺自然频率） | 32 kHz | DS Table 8/12 |
| 加速度噪声密度 | 150 µg/√Hz | 70 µg/√Hz | DS Table 7 |
| 陀螺噪声密度 | 15 mdps/√Hz | 2.8 mdps/√Hz | DS Table 8/12 |
| 供电 VDD/VDDIO | **1.71–3.6 V**（typ 1.8 V） | 1.71–3.6 V | DS Table 6 |
| 工作温度 | −40 ~ +85 °C | −40 ~ +85 °C | DS Table 7/8 |
| 接口 | I²C / I³C / SPI(3/4 线) | I²C / I³C / SPI | DS §1.4/§16 |
| I²C 最高 | 400 kHz（Fast Mode） | 1 MHz | DS Table 14 |
| SPI 最高 | 15 MHz | 24 MHz | DS Table 14 |
| 中断脚 | INT1 + INT2，事件可软件选路 | 2 路 | DS Fig.2 / §9.6 |
| 片上事件引擎 | Tap / Any-/No-/Significant-Motion / WoM / Pedometer | APEX：同类 | DS §9–§12 |
| I²C 地址 | SA0 高=0x6A，低=0x6B | 0x68/0x69 | DS §16.3.1 |

> DS = QMI8658C Datasheet Rev A。陀螺 ODR 设到 >1 kHz 时 datasheet（Table 12 note 11）明确警告噪声显著上升——见"人工复核"节。

### 片上事件引擎（决定能硬件判定碰撞/抬起的关键）

QMI8658C 封面自称 "Motion Co-Processor"，内含 M0+ MCU，以下引擎都能直接产生中断，配置通过 CTRL9 命令两段式写参数：

| 引擎 | DS 章节 | 对本项目用途 |
|---|---|---|
| Tap（单/双击） | §10 | 碰撞检测（撞一下 = 单击峰） |
| Any-Motion / No-Motion | §9 | 抬起 / 被搬动时姿态突变触发；放下静止触发 No-Motion |
| Significant-Motion | §9.1.3 | 持续被搬动 |
| Wake-on-Motion (WoM) | §12 | 低功耗待机被碰醒 |
| Pedometer（计步） | §11 | 本项目用不上，但说明引擎成熟 |

注意：Motion / Tap / Pedometer **只在 Non-SyncSample 模式工作**（DS §9 开头）。

## 引脚接线

[`BOARD_MAPPING.md`](BOARD_MAPPING.md) 里 IMU 走的是 **SPI（4-wire）**，与原 ICM-42688-P 的接法一致。QMI8658C 同样支持 4-wire SPI，**可直接顶替原引脚，不需要改 BOARD_MAPPING 的 GPIO 分配**。

### 方案 A：SPI（与 BOARD_MAPPING 现状一致，推荐）

| 信号 | 开发板 GPIO | 母排脚 | QMI8658 模块脚 | 备注 |
|---|---|---|---|---|
| `IMU_SCLK` | IO51 | J3-51 | SCL（= SPC，SPI 时钟） | 4-wire SPI 下 SCL 脚作 SPC |
| `IMU_MOSI` | IO50 | J3-50 | SDA（= SDI，主→从） | 4-wire SPI 下 SDA 脚作 SDI |
| `IMU_MISO` | IO49 | J3-49 | ADO（= SDO，从→主） | 4-wire SPI 下 SA0/ADO 脚作 SDO 输出 |
| `IMU_CS` | IO22 | J4-22 | （模块 CS；若模块未引出见下） | 片选，低有效 |
| `IMU_INT` | IO23 | J4-23 | INT | 中断；模块通常只引出一路（对应 INT1 或 INT2） |
| 3V3 | 开发板 3V3 脚 | — | VCC | 模块带 LDO，3.3V 直供 |
| GND | GND | — | GND | 公共地 |
| — | — | — | XDA / XCL | 辅助 I²C 主口（外挂磁力计用），本项目悬空 |

> ⚠️ **模块脚位别照搬芯片脚名**：4-wire SPI 模式下，芯片的 SCL/SDA/SA0 分别复用为 SPC/SDI/SDO（DS Table 2）。但**紫色 GY 模块的引脚是按 I²C 丝印的（SCL/SDA/ADO），不一定把芯片 CS 引出来**——很多 QMI8658 模块只引 8 脚、默认接成 I²C。**下单/接线前必须实物确认这块模块到底有没有 CS 脚、能不能进 SPI 模式**（见"人工复核"节）。如果模块焊死成 I²C，就走方案 B。

### 方案 B：I²C（模块只支持 I²C 时的回退）

模块默认 I²C 接法：SCL→IMU_SCLK 脚改作 I²C SCL、SDA→I²C SDA、ADO→地址选择、INT→IMU_INT。但 **BOARD_MAPPING 当前没有给 IMU 留 I²C 走线**（左排 I²C0 IO7/8 是板载 ES8311 共用、不可碰；I²C1 IO20/21 在右排给了 BH1750）。

若必须走 I²C，两条路：
1. 把 QMI8658 挂到 **I²C1（IO20/21）与 BH1750 共总线** —— 地址不冲突（QMI 0x6A/0x6B，BH1750 0x23/0x5C），电气可行，但要改 BOARD_MAPPING。
2. 维持独立总线则要新分配两个 GPIO 做 I²C —— 改动更大。

**任选都需先改 BOARD_MAPPING 真值源再动电路**，不在本文擅自决定。

## 驱动选择

QMI8658 在 ESP 生态有三套可用驱动，按推荐度排：

| 驱动 | 来源 | 接口 | 覆盖 | 取舍 |
|---|---|---|---|---|
| **lewisxhe/SensorLib** | GitHub 225★ / registry `lewisxhe/sensorlib` | I²C + SPI | 最全：BasicRead / FIFO / **Pedometer / Tap / WakeOnMotion** / SyncMode 等 | 要用事件引擎就上它；最活跃、例程最多 |
| **waveshare/qmi8658** | ESP 官方 Component Registry | I²C | 量程/ODR/原始数据/温度/时间戳，**未暴露事件引擎** | 只读原始数据时最省事，`idf.py add-dependency "waveshare/qmi8658^2.0.0"` |
| **esp-idf-lib/qmi8658c** | GitHub / registry，BSD-3 | I²C | 基础读取为主 | 备选，社区小 |

- **要硬件 Tap / WoM 中断（碰撞/抬起）→ 选 SensorLib**（含对应例程，且支持 SPI）。
- **只读原始数据自己算 → Waveshare 官方组件最简单**。
- 对比 ICM-42688-P：ICM 没有 Espressif 官方 registry 组件，主流是自己拉 InvenSense C 驱动移植。**驱动生态上 QMI8658 反而更顺手。**

## 备用方案

按"真买得到模块 + ESP-IDF 驱动现成"排序：

1. **LSM6DSO / LSM6DSOX（ST）— 首选备用。** 6 轴、I²C+SPI、3.3V，片上 FSM/MLC + Tap/WoM/free-fall 引擎，噪声介于 QMI 与 ICM 之间。ST 官方 C 驱动 + 社区驱动易移植，淘宝 GY 模块常见、LCSC 有货。货源稳、不踩假货坑。
2. **正品 ICM-42688-P 模块 — 性能天花板。** APEX 引擎齐全、噪声最低。代价：淘宝改标/假货多，认正品；驱动要自己移植 InvenSense。性能要顶配才选。
3. **MPU6050 — 仅临时验证。** 最便宜、驱动遍地，但已停产、噪声温漂差、无现代事件引擎。不进正式 BOM。
4. **BMI270（Bosch）— 不推荐做省事备用。** 初始化要加载固件 blob、配置最繁琐，ESP-IDF 现成驱动不如前几个顺。

## 下单 / 接线前必须人工复核（红线项，别赌）

1. **模块到底支不支持 SPI / 有没有 CS 脚。** 紫色 GY 模块多按 I²C 8 脚出，**很多没把芯片 CS 引出来**。先看实物丝印/原理图：有 CS → 走方案 A（与 BOARD_MAPPING 一致）；没有 CS → 只能 I²C，走方案 B 并改真值源。**这条不确认就别下结论接线。**

2. **I²C 地址冲突。** QMI8658 地址由 ADO/SA0 决定：高=0x6A、低=0x6B（DS §16.3.1）。若走方案 B 与 BH1750（0x23/0x5C）共 I²C1，地址不冲突；但要确认模块上 ADO 默认上/下拉到哪一边，别两颗 IMU 或别的从机撞地址。

3. **3.3V vs 1.8V。** datasheet 推荐 VDD/VDDIO 1.71–3.6 V，**典型工作点是 1.8 V**，电气表里的电流/性能都在 1.8V 测。**模块**带 LDO+电平（VCC 标 3.3–5V），吃开发板 3V3 没问题；但如果将来要上**裸芯片**进 PCB，得自己确认 1.8V 供电与电平匹配，别直接照模块经验。本版用模块 → 3.3V 直供 OK。

4. **INT 路由。** QMI8658 有 INT1+INT2，每个事件可软件选走哪路（CTRL8.bit6）。模块通常**只引出一路 INT**——要确认它内部接的是 INT1 还是 INT2，固件里把目标事件路由到那一路，否则中断永远不来。BOARD_MAPPING 的 `IMU_INT`(IO23) 接模块这一路即可。

5. **ODR > 1 kHz 噪声。** datasheet（Table 12 note 11）明确：陀螺 ODR 设到 1 kHz 以上时噪声显著上升，不建议对噪声敏感的应用拉到 >1 kHz。我们做事件/振动阈值，**别盲目把 ODR 拉满**；按需求设（碰撞/抬起几百 Hz 足够，振动判定按目标频段定，留足裕量即可）。

---

### 出处

- QMI8658C Datasheet Rev A（QST 官方，文档号 13-52-27）：https://www.qstcorp.com/upload/pdf/202210/13-52-27%20QMI8658C%20Datasheet%20Rev%20A%20(1).pdf
- lewisxhe/SensorLib（QMI8658 驱动，含 Tap/WoM/Pedometer 例程，I²C+SPI）：https://github.com/lewisxhe/SensorLib
- Waveshare QMI8658 ESP 官方组件：https://components.espressif.com/components/waveshare/qmi8658
- esp-idf-lib/qmi8658c：https://github.com/esp-idf-lib/qmi8658c
- ICM-42688-P Datasheet（TDK，对比噪声/量程）：https://product.tdk.com/system/files/dam/doc/product/sensor/mortion-inertial/imu/data_sheet/ds-000347-icm-42688-p-v1.6.pdf

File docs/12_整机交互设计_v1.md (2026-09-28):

# 12 · 整机交互设计 v1（行为 / 情绪 / 运动语言）

> **文档性质：行为设计与开发记录。功能完成度以 README 和 docs/00 为准。**
>
> 目标：把整机全部感知硬件（相机 / IMU / 环境光 / 电流+编码器 / 触摸屏 / 麦克风 / 上位机链路）变成**可感知的生命感**，而不是一堆各自为战的 demo。
> 设计落在现有架构上（soul 状态机 / motion IK / face 表情 / telemetry 事件总线 / companion WS，见 00 §2–§3），每项都标注固件改动点与落地分期（§9）。协议改动全部走「只增不改」（09 铁律）。
> 本文是**行为真值源**：调阈值、加场景先改这里，再改代码。

---

## 0. 设计目标：什么让人觉得「智能」

不是算力，是**反应的质感**。七条原则，后文每个场景都能对回来：

| # | 原则 | 落点 |
|---|---|---|
| P1 | **即时回应**：任何刺激 → 可见反应 ≤300ms | 事件表情走 NOW；IMU/触摸走中断不轮询 |
| P2 | **动作有意图感**：先转头再移动、缓入缓出，像动物不像小车 | 运动原语带斜坡；朝向优先（§5） |
| P3 | **不机械重复**：同一刺激的反应带 ±15% 参数抖动与变体 | 原语参数抖动；反应变体表（§4） |
| P4 | **有内在状态**：行为随「精力/亲近感」慢变量可感知变化 | 情绪引擎两变量（§3） |
| P5 | **有短期记忆**：刚发生的事影响下一次反应 | 事件近因权重（§3.4） |
| P6 | **安静的存在感**：待机不是死机，有「呼吸」 | 微动作层（§2 R5、§4-S3） |
| P7 | **可预测的安全**：被抓住/抬起/卡住永远立刻停 | 反射层最高优先（§7），这是信任的来源 |

反面清单（做了会立刻显蠢）：反应延迟 >500ms；同一动作分毫不差地重复；无人时完全静止；被抬起还在蹬轮子；表情高频抖动切换。

## 1. 输入总表（硬件信号 → 派生特征 → 事件）

| 硬件 | 原始信号 | 派生特征 | 进事件总线 | 分期 |
|---|---|---|---|---|
| OV5647+vision | present, cx/cy, area, frontal（8fps） | 接近速度 `d(area)/dt`、驻留时长、丢脸时长 | `FACE_PRESENT/LOST`（已有） | 已落地 |
| QMI8658（I²C1，INT=IO23） | 片上 Tap / Any-Motion / WoM 中断；加速度/角速度 | 单击/双击；**抬起**（WoM+失重/无地面反馈）；**放下**（静置 1.5s）；**倾斜**（pitch/roll） | 新增 `TAP` `LIFTED` `PLACED` `TILT` | I1 |
| BH1750（I²C1 0x23） | lux（1Hz 轮询够用） | 暗/亮判定（滞回+持续时间） | 新增 `DARK` `BRIGHT` | I1 |
| INA219+编码器 | 总电流 mA；三轮计数/RPM | **堵转**（高流+不动+在驱动）；**被拨轮**（未驱动却有计数） | 新增 `STALL` `WHEEL_MOVED` | I1/I2 |
| FT6x36 触摸屏（I²C0 0x38，板载未启用） | 触点坐标/按下时长 | 戳脸（短触）/ 长按 | 新增 `TOUCH{x,y,long}` | I1 |
| 麦克风（ES8311） | RMS 能量 | 唤醒（现有 VAD）；**响度突变**（惊吓） | `WAKE`（已有）+ 新增 `LOUD` | I1（LOUD） |
| companion WS（控制向） | 9 命令 | 远程刺激（§6） | 复用 ack/事件 | 已落地 |
| companion WS（**感知向**，`pc_state`，09 v1.1） | activity / idle_s / focus / media / dnd（变化即发+5s 心跳） | **主人电脑侧状态**：专注/挂机/锁屏/开会/在放媒体 | telemetry 快照 `pc{}`（15s 新鲜度，过期回退纯视觉） | I0*（设备侧）+ 上位机 PC 状态上报 |
| 时钟 | 开机毫秒 / SNTP | 无交互计时、昼夜（有网时） | — | 已落地 |

> 多人场景：V1 沿用「取最大脸」，不做身份识别（P2 再议）。麦克风方向感：板载单麦，不做声源定位（已砍）。

## 2. 分层架构与意图仲裁（含 teleop 覆写修复）

现状问题：`soul_task` 每 100ms 无条件 `motion_set_intent()`，companion 的 teleop 会被立刻覆写。本设计以**仲裁器**根治，同时承载全部新行为：

```
输入事件 ──► 反射层 R0（同步路径，不过状态机）─────────┐
                                                        ▼
soul 行为层 R4 ──┐                          ┌──────────────────┐
teleop 租约 R3 ──┼─► intent 仲裁器（motion 内）│ 取最高优先活跃源  │─► IK ─► 电机
会话姿态 R2 ────┘   每源带 ttl 租约           └──────────────────┘
FAULT   R1 ─────► 恒零 + STBY 视情况
微动作  R5 ─────► 仅当 R2–R4 输出为零时叠加小幅调制
```

**优先级（高抢低，全部带租约超时回落）**：

| 级 | 源 | 说明 |
|---|---|---|
| R0 | 反射：堵转→STBY、LIFTED→轮全停、\|tilt\|>8°→停 | 绕过仲裁直接闸门，任何状态下生效 |
| R1 | FAULT / estop | 意图恒零，锁定至 `clear_fault` |
| R2 | 语音会话（LISTEN/THINK/SPEAK） | 平移为零，仅保留「朝人转正」的 wz |
| R3 | teleop（租约 = `ttl_ms`，缺省 300ms，续租式） | **修复点**：租约存活期内 soul 不得写 intent |
| R4 | 行为层（soul 状态机输出） | 现有 GAZED>RETREAT>APPROACH/ENGAGE>… |
| R5 | 微动作（idle 呼吸感） | 幅度 ≤R4 正常输出的 20%，可被一切打断 |

**固件改动点**：`motion_set_intent(source, vx, vy, wz, ttl_ms)` 加源与租约参数（旧签名保留为 R4 源的别名，兼容现有调用）；仲裁在 motion 组件内做，soul 不感知 teleop 存在。

## 3. 情绪引擎（轻量：两个慢变量，拒绝过度建模）

### 3.1 慢变量

| 变量 | 含义 | 升 | 降 | 可感知效果 |
|---|---|---|---|---|
| `energy`∈[0,1] | 精力 | 静置恢复 +0.1/10min；DOZE 加速恢复 | 运动/会话消耗；亮暗周期跟随 | 低→动作变慢变少、sleep 倾向；高→微动作频繁 |
| `social`∈[0,1] | 亲近感 | 每次正向互动 +0.05（gazed/对话/触摸） | 独处指数衰减 τ=10min | 高→接近更快更主动、tip 更热络；低+有人→更谨慎试探 |

两个都够「让人察觉它今天不一样」，又不至于调不动。初值 0.5，断电不保存（V1；持久化列 P2）。

### 3.2 表情资产现实约束

现有素材只有 **5 个 clip：waiting / o / sad / sleep / think**（各 4.5–15s 循环，07）。表达维度靠三件事扩展：**clip 选择 + 运动风格 + tip 文案**。`happy`、`blink`、左右瞥素材列 P1 补做（07 P3），本文场景先全部落在 5 clip 上。

### 3.3 表情切换规则（防抖是「不蠢」的底线）

| 优先级 | 类别 | mode | 规则 |
|---|---|---|---|
| E1 | FAULT → `sad` | NOW | 锁定至故障解除 |
| E2 | 事件瞬时（TAP/LIFTED/TOUCH/惊讶 → `o` 等） | NOW | **最短保持 800ms**，同类事件不重触发（1.5s 冷却） |
| E3 | 上位机 `set_emotion` | 按命令 | 10s 租约（现有），期间抑制 E4/E5、不抑制 E1/E2 |
| E4 | 会话（LISTEN/SPEAK→`waiting`、THINK→`think`） | FADE | 会话态期间稳定持有 |
| E5 | 基调（状态机+慢变量：DOZE→`sleep`、失落→`sad` 短暂、默认→`waiting`） | FADE | 切换最小间隔 2s |

同名表情不重发（避免 clip 重头播）；全部切换走现有 `face_set_emotion` 队列，无新机制。

### 3.4 短期记忆（近因权重，P5 原则）

固定长度事件环（最近 60s）：
- 60s 内第二次 `TAP` → 反应升级：退更远 + tip 从「呀」变「别敲啦」+ `social -0.1`。
- 刚结束 GAZED 回避 → 30s 内不再触发 GAZED（现有 1.5s 回避窗延长为记忆化冷却）。
- 刚被抬起放下 → 10s 内动作幅度减半（「惊魂未定」）。

实现 = soul 内一个 8 槽 `(event, ts)` 环形数组 + 查询函数，几十行的事。

### 3.5 注意力融合策略（视觉 × PC 状态 → 交互许可等级）

`pc_state` 是不依赖相机的第二路在场/注意力传感器。soul 每 tick 先算**交互许可等级**，再跑状态机——等级只调策略参数，不加新状态：

| 视觉 | PC 状态（新鲜） | 判定 | 许可等级 → 行为调制 |
|---|---|---|---|
| 有人 | `dnd` 或 `focus∈{work,meeting}` 且 active | 主人在专注 | **勿扰**：禁主动接近与邀玩，微动作频率 ×0.3，tip 静默；仅被直视（GAZED）或被触摸时回应 |
| 有人 | `meeting` | 开会 | **静默**：勿扰基础上运动全停（微动作也停），像「懂事地坐好」 |
| 有人 | idle_s > invite 阈值 | 主人闲着/挂机 | **主动**：允许 S17 邀玩，接近更积极（social 加成） |
| 有人 | `media` | 主人在娱乐 | **陪伴**：不打扰对话类 tip，允许 S19 节奏摆 |
| 无人 | active | 人在电脑前但不在视野 | **知情等待**：不演失落（S6 跳过 sad），朝屏幕方向偶尔张望 |
| 无人 | locked / idle 很久 | 真离开 | **休息**：加速进 DOZE（S18） |
| 任意 | 无 PC 信息（>15s 未更新） | 单源 | 回退 §4 纯视觉行为（v1 现状） |

**原则**：PC 状态只做「许可/克制」的调制器，**永不直接触发动作**（避免电脑上一个窗口切换就让机器人抽动）；触发权始终在视觉/IMU/触摸等物理刺激手里。dnd 的优先级最高——用户手动说安静，比一切推断都硬。

## 4. 交互场景库

格式：**触发 → 时间轴（运动/表情/tip）→ 退出**。角标 = 落地分期（§9）。阈值全部走 SD 配置（§8），此处为默认值。

### S1 开机仪式 ⁰
上电 → `sleep`（1.5s）→ `o`（睁眼，0.8s）→ 慢转 ±20° 张望一圈（接轮后）→ `waiting` + tip「NanoSoul ✓」。**第一印象即生命感**，且掩盖子系统启动时序。

### S2 发现人 → 迎接 ⁰′²
- 触发：`FACE_PRESENT`（IDLE/DOZE 中）。
- 时间轴：`o`(NOW, 0.8s) → wz 朝人转正（`wz=-0.8·cx`，现有）→ social>0.6 时向前 nudge 3cm¹ → `waiting`(FADE)。DOZE 中被发现：先「揉眼」（sleep→o 慢 FADE 1s）再执行，唤醒感。
- 退出：进入 S3/S4 常规循环。

### S3 陪伴驻留（ENGAGE 里的呼吸感）⁰′²
- 触发：ENGAGE 稳定 >5s。
- 微动作（R5，泊松间隔 8–20s 随 energy）：wz 正弦小摆 ±5°（1.2s）｜歪头 = 单侧 ±8° 停 0.5s 回正｜tip 偶发短句（「嗯嗯」「在呢」，频率低于动作，间隔 ≥60s）。
- **全程 area/cx 继续闭环**（人挪动就跟随转向）——微动作叠加不中断跟踪。

### S4 靠近 / 退后（sweet spot，现有行为的质感升级）²
- 现有：area<near_lo→APPROACH、>near_hi→RETREAT。升级三点：
  1. **先转正再平移**（|cx|>0.15 时只转不走，P2 原则）；
  2. 速度随偏差比例（远快近慢，到位前 0.3s 线性减速，不急停）；
  3. **APPROACH 位移预算**：单次 ≤15cm（编码器里程），预算耗尽仍不达标 → 停下歪头（tip「够不着…」），防无悬崖传感器坠桌（§7）。
- `d(area)/dt` 快速增大（人猛凑近）→ 插入 `o`(NOW) + 后退 nudge 5cm，比单纯 RETREAT 更「被吓到」。

### S5 凝视 → 害羞（现有增强）⁰′²
- 现有：frontal>0.7 持续 1.5s → GAZED，退避 vx=−0.5。
- 升级：退避改为 **retreat_shy 原语**（后退 6cm + 转开 15°，见 §5）+ `o`(NOW) + tip 变体池（「别一直盯着看啦」「我会害羞的」随机）；记忆化冷却 30s（§3.4）；social +0.05。

### S6 人离开 → 张望失落 ⁰′²
- 触发：`FACE_LOST` 持续 >2s（滤瞬时丢检）。
- 时间轴：wz 慢扫 ±30° 两个来回「找人」（3s）² → 找回 → S2；找不到 → `sad`(FADE, 5s) + tip「走了呀…」→ `waiting` → 计时进 IDLE。social 衰减开始计时。

### S7 被敲击 / 碰撞（IMU Tap）¹
- 单击：`o`(NOW) + 后退 nudge 4cm² + tip「呀」。60s 内第二次：退 8cm + tip「别敲啦」+ social −0.1（§3.4）。
- 双击（片上 double-tap）：**彩蛋**——表情轮播下一个 clip + tip「换个脸～」。给用户一个「发现隐藏功能」的时刻。
- 运动中的碰撞（Tap 且正在平移）：立即停 0.5s → `o` → 反向 nudge → 恢复原行为。

### S8 被抬起 / 放下（安全 + 表演双重）¹
- 抬起判定：WoM 中断 + 加速度模长偏离 1g >0.15g 持续 300ms（接轮后再加「duty>0 但编码器无地面反馈」旁证）。
- 时间轴：**R0 反射轮全停（≤50ms，先于一切表演）** → `o`(NOW) + tip「哇——放我下来」→ 悬空期间进 LIFTED 态（新增态，见 §4 末注），运动恒零，表情保持 `o`。
- 放下：静置（加速度方差小）1.5s → `PLACED` → 眨眼感（o→waiting FADE）→ 10s 惊魂期动作减半 → 回 IDLE/ENGAGE。

### S9 被拨轮 / 被推动 ¹′²
- 触发：`WHEEL_MOVED`（未驱动却有编码器计数，>1/4 圈）。
- 反应：`o`(NOW) + 朝被拨的轮子方向微转（三轮计数能分出哪个轮）+ tip「咦？」。连续拨弄 3 次 → 判定「在玩我」→ tip「好玩吗 :P」+ social +0.05。**把干扰变成互动。**

### S10 暗光瞌睡 / 亮光醒 ¹
- lux <10 持续 30s（滞回：>30 才算亮）→ **DOZE 态**（新增）：`sleep`(FADE)，微动作停，检测帧率可降半省功耗，energy 加速恢复。
- 退出：`BRIGHT` / 任何刺激（TAP/TOUCH/WAKE/FACE_PRESENT）→ S2 的「揉眼」唤醒序列。夜里被强光突然照 → 先 `o`「被闪到」再醒。

### S11 无聊自主行为（IDLE 久了）²
- 触发：IDLE >90s，泊松采样（λ 随 energy：精力高约 45s 一次，低则数分钟）。
- 行为池（随机+不重复上一个）：慢扫张望（wz ±30°）｜原地小转圈 360°（低速）｜短打盹 10s（sleep→自醒）｜tip 自言自语（「今天真安静」）。
- **硬约束：自主行为只做零位移动作（旋转/摆动），绝不平移**——无悬崖传感器，无人监督时不移动（§7）。

### S12 语音会话姿态 ⁰′²
- LISTEN：身体朝人转正锁定（R2 只留 wz）+ `waiting` + tip「(听)」；SPEAK：随音频播放做 wz ±3° 轻微节奏摆²；THINK：静止 + `think`。会话全程忽略 S3 微动作。现有状态机不动，只加姿态输出。

### S13 上位机交互反馈（详表见 §6）⁰
远程命令不能只有静默执行——设备侧要有可见回应，否则演示时「上位机在控制」这件事本身不可见。

### S14 堵转 / 卡住 ¹′²
- 判定：单轮电流 >350mA 持续 200ms（实测堵转 400mA/个）且 |rpm|<5 且 duty>30% → **R0：STBY 拉低** → FAULT + `sad` + tip「卡住了，帮帮我」。
- 恢复：3s 后自动试探解除一次（duty 25% 反向 0.3s）；连续 3 次失败 → 锁定等 `clear_fault`（上位机或触摸长按 5s¹）。

### S15 低电量（电量计接入后）³
IP5306/电量寄存器 <20% → 基调转 `sad` 倾向 + tip「有点饿了」；<10% → 运动禁用只剩表情。V1 无 PCB 版无电量计，仅列设计。

### S16 专注勿扰（PC：work/meeting/dnd）⁰*
- 触发：许可等级进入「勿扰/静默」（§3.5）。
- 行为：不主动接近、不邀玩、微动作降频（meeting 全停）；人凑近看它仍正常回应（是懂事，不是死机）；退出专注后第一次对视 → tip「忙完啦？」（近因记忆，§3.4）。
- **这是「智能感」性价比最高的场景**：机器人「知道你在忙」远比会卖萌更像有脑子。

### S17 挂机邀玩（PC idle + 人在视野）⁰*′²
- 触发：`idle_s > 300`（可调）且 present 且非勿扰，泊松采样防每次准点骚扰。
- 时间轴：歪头（tilt_glance）→ 前进 nudge 3cm² → tip 变体池（「休息一下？」「陪我玩会儿」）→ 30s 无回应（无对视/无触摸）→ 安静退回原位，1 小时内不再邀（记忆）。social 高时更频繁，低时只歪头不上前。

### S18 锁屏离席 / 解锁迎接（PC locked ↔ active）⁰*
- `locked`：预期离席——随后 `FACE_LOST` **跳过 S6 失落表演**（它「知道」你是去忙了），直接安心加速进 DOZE。
- `locked→active`（解锁）：预期回归——提前退出 DOZE、朝惯常方向张望²；随后 `FACE_PRESENT` → S2 迎接升温版（tip「回来啦」）。**预期→兑现的闭环是「它记得我」的核心错觉。**

### S19 陪看/节奏（PC media=true）⁰*′²
- 人在 + media：进「陪伴」等级——对话类 tip 静默，偶发 wiggle 轻摆（像跟着晃）²，凝视阈值放宽（看屏幕的人侧脸多，别误触 GAZED 退避）。

> S16–S19 均为策略调制，不新增状态机顶层态；⁰* = 设备侧 I0 可做，但依赖上位机 PC 状态上报（可并行）。

> **状态机改动**：新增 `LIFTED`、`DOZE` 两个顶层态（协议 `soul` 字段是字符串、取值只增，符合 09 前向兼容铁律；上位机对未知态按原名显示）。其余场景全部是现有 9 态内的行为/表情/tip 扩展，不动枚举。

## 5. 运动语言（原语库）

全向轮不该只会「前进后退」。原语 = 参数化 `(vx,vy,wz)(t)` 曲线，统一带**缓入缓出斜坡（100ms）**与 **±15% 参数抖动**（P3 原则）：

| 原语 | 曲线 | 用途 | 默认参数 |
|---|---|---|---|
| `turn_face` | wz=-k·cx 比例控制 | 朝人转正（持续） | k=0.8（现有） |
| `nudge(dir,d)` | 单方向梯形速度 | 小步进/退缩 | d=3–8cm，duty≤30% |
| `retreat_shy` | 后退 + 同时转开 | S5 害羞 | 退 6cm 转 15° |
| `wiggle` | wz 正弦 1–2 周期 | 开心/歌唱节奏 | ±5°，1.2s |
| `tilt_glance` | 单侧转 + 停 + 回正 | 歪头（好奇） | ±8°，停 0.5s |
| `scan` | wz 慢速三角波 | 张望/找人 | ±30°，0.3rad/s |
| `spin` | 原地 360° | 自主行为彩蛋 | 低速一圈 |
| `shiver` | wz 高频小幅 | 害怕（P1 素材配套时用） | ±2°，4Hz，0.8s |
| `approach_prop` | vx 随 area 误差比例+减速带 | S4 靠近 | 见 §4-S4 |

安全包络（原语层强制，仲裁器之外再兜一层）：duty ≤`motion.max_duty_pct`（默认 40%）；加速度斜坡 ≥100ms；**任何原语可被 R0–R3 即时打断**；平移类原语必须声明位移预算并用编码器里程结算。

## 6. 上位机数据接收：命令 → 设备反馈表

| 命令 | 设备可见反馈（新增设计） | 备注 |
|---|---|---|
| `ask{text}` | 现有：THINK + tip「…」→ 回复上 tip | 不变 |
| `set_emotion` | 表情租约 10s（现有）+ **tip「(遥控表情)」小字 2s** | 演示时可解释屏幕为何变脸 |
| `teleop` | 租约激活期间：`o`(E2) + tip「被遥控中」；租约过期自动回基调 | 依赖 §2 仲裁修复 |
| `estop` | FAULT + `sad` + tip「急停」 | 现有 + tip |
| `clear_fault` | 眨眼感恢复（sad→waiting FADE）+ tip「恢复啦」 | |
| `config_reload` | tip「配置已更新」2s | |
| `set_overlay` | HUD 开关（现有），无表情反馈 | |
| `get_snapshot` / `selftest` | 无打扰（纯数据） | |
| 客户端连接/断开 | **不打扰**（只进日志/HUD），机器人不该对「被观察」有反应 | |

**接收向（`pc_state`，09 v1.1）**：companion 解析 → `telemetry_set_pc()` 写入快照 `pc{activity,idle_s,focus,media,dnd,fresh}` → soul 每 tick 按 §3.5 算许可等级；15s 无更新自动降级为「无 PC 信息」。HUD 的 NET 行追加 pc 摘要（如 `PC:work/idle312`），调试时一眼看到融合输入。**不为 pc_state 回 ack、不发事件**——它是连续状态不是离散刺激。

**遥测加法（协议只增）**：`state` 帧新增 `beh`（当前行为原语名，string）与 `mood{energy,social}`（两位小数）——上位机 F2 仪表盘可画慢变量曲线，调参时肉眼可见；新增事件 `tap/lifted/placed/dark/bright/touch/wheel_moved/stall`（上位机 F3.1 通用渲染已兼容未知事件名）。

## 7. 安全与反射（P7：信任来自「永远立刻停」）

| 反射 | 判据 | 动作 | 延迟目标 |
|---|---|---|---|
| 堵转 | §4-S14 判据 | STBY 拉低（硬闸） | ≤250ms |
| 抬起 | §4-S8 判据 | 轮全停（意图恒零 + 可选 STBY） | ≤50ms（INT 驱动） |
| 倾斜 | \|pitch\| 或 \|roll\| >8°（桌沿探出/翘起前兆） | 停轮 + 缓退 2cm（若仍着地） | ≤100ms；**可靠性需上板标定，标定前只停不退** |
| teleop 失联 | 租约过期 | 意图清零 | =ttl_ms |
| 无悬崖传感器的总补偿 | ①自主行为零位移（S11）②APPROACH 位移预算+低速（S4）③倾斜反射兜底 | — | 设计级约束 |

恢复策略统一：反射触发 → 事件上报 → 表情/tip 表演 → 按场景自动恢复或等人工解除。**表演永远在停车之后**，顺序不能反。

## 8. 参数表（SD 配置新增键，全部热调）

```json
"behavior": { "near_lo":0.04, "near_hi":0.18, "frontal_thresh":0.70, "gaze_hold_ms":1500,
              "gaze_cooldown_s":30, "idle_scan":false, "autonomy":true, "autonomy_idle_s":90 },
"mood":     { "enabled":true, "energy_init":0.5, "social_init":0.5, "social_tau_min":10 },
"imu":      { "tap_th":3, "lift_g_dev":0.15, "lift_hold_ms":300, "place_still_ms":1500, "tilt_deg":8 },
"light":    { "dark_lux":10, "bright_lux":30, "dark_hold_s":30 },
"protect":  { "stall_ma":350, "stall_ms":200, "stall_retry":3 },
"move":     { "approach_budget_cm":15, "nudge_cm":4, "ramp_ms":100, "jitter_pct":15 },
"pc":       { "stale_s":15, "respect_dnd":true, "quiet_work":true, "quiet_meeting":true, "invite_idle_s":300, "invite_cooldown_min":60 }
```

上位机 `config_reload` 即生效——**调行为不用重刷固件**，这是联调效率的关键。

## 9. 实现映射与分期

> **落地状态（2026-07-06）：I0–I2 已全部代码实现并板外 `idf.py build` 通过**（8 里程碑 commit，纯逻辑自检 6 项恒绿）。I1 待接线实测（imu/light/touch），I2 待接轮真机验证（Captain）。实际实现相对下表的调整：IMU 用**软件检测**（QMI8658 裸驱动 + 纯检测器，非片上 Tap/WoM，INT 脚不接；片上事件引擎留 P1）；触摸复用现有 `components/touch` 裸驱动并新增 `touch_router` 单读者。

| 期 | 前置 | 内容（组件级落点） | 状态 |
|---|---|---|---|
| **I0 纯软件** | 无 | motion 仲裁器+租约（修 teleop 覆写）；表情规则引擎 E1–E5 + 防抖（`soul_expr`）；短期记忆环；S1/S2/S3/S5/S6/S12/S13 表情+tip；`beh`/`mood` 遥测；**pc_state 消费**（companion→telemetry `pc{}`→§3.5 许可等级）；自检 arbiter/expr/fusion_sim | ✅ 已实现 |
| **I1 接传感**（杜邦即可，不用接轮） | IMU/BH1750/触摸接线 | 新组件 `board_i2c1`（共享总线）、`imu`（QMI8658 软件检测）、`light`（BH1750 轮询）、`touch_router`（FT6x36 单读者）；9 交互事件入总线；S7/S8/S9/S10 全量；LIFTED/DOZE 两态；自检 imu_probe/light_read/touch_probe/imu_sim | ✅ 已实现，待接线实测 |
| **I2 接轮**（M1 引脚先挪出 IO24/25） | 电机接线 + `motion.enabled=true` | 运动原语库（`soul_prim`）；S4 比例接近+先转正；S11 自主行为（零位移）；S3 微动作（MICRO 源）；S14 堵转闭环（`app_sense` stall FSM）；自检 prim/stall_sim | ✅ 代码就绪，待接轮验证 |
| **I3 打磨** | P1 素材（happy/blink） | 情绪慢变量调参（靠上位机 mood 曲线）；表情素材扩充接入；音效；IMU 片上事件引擎；S15（电量计接入后）；位移预算（move.approach_budget_cm 已入配置，接轮后接编码器里程） | ⬜ 开放 |

各期均可独立演示、独立验收；I0 与 I1 不依赖接轮，**当前硬件状态下就能把「智能感」做出 70%**（表情/tip/事件反应都不需要轮子）。

## 10. 智能感验收清单（演示视角，逐条可打勾）

1. 走进视野 1s 内：它「惊讶 → 转向我 → 安顿下来」。
2. 站着不动看它 2 秒：它害羞躲开，且 tip 每次说得不一样；30s 内再盯，它不再上当。
3. 敲它一下：立刻「呀」+ 缩一下；再敲：反应明显升级。
4. 拿起来：轮子**瞬间**停 + 惊慌脸；放下：定 1.5s 神才恢复。
5. 关灯 30s：睡着；开灯：揉眼醒来。
6. 拨它轮子玩：它发现了，还觉得好玩。
7. 谁都不理它 2 分钟：它自己找事做（张望/转圈/打盹），且每次不一样。
8. 上位机发 teleop：它「被遥控中」表情上脸，松手 300ms 内自己停。
9. 卡住它：立刻断电停转 + 求助脸，挪开障碍它自己再试。
10. 以上全程断网成立（除语音对话与 PC 融合）——**杀手锏话术的具象版**。
11. 我在电脑上开会/开勿扰：它真的不来烦，凑过去看它、它也只安静回望——**「它知道我在忙」**。
12. 电脑挂机 5 分钟：它歪着头凑过来邀玩；不理它就安静退回去，且一小时内不再来第二次。
13. 锁屏起身：它不演失落、直接安心打盹；解锁坐下：它已经在朝我这边张望了。

---

**与其他文档的关系**：本文新增的协议字段/事件按 09 加法规则演进，上位机侧按「未知即忽略/通用渲染」处理；落地推进时同步更新 00 §1.2 功能清单状态列与 §5 差距清单。

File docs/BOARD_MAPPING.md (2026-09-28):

# BOARD_MAPPING — 引脚分配表（模块版 ↔ ESP32-P4-WIFI6）

> 本文记录当前实物（现成模块 + 杜邦线）的引脚分配。修改引脚、总线或供电时，需要同步更新本文、`CLAUDE.md` 固件节和 `main/drv_*.c`。
> 已按 ESP32-P4 datasheet v1.3、ESP-IDF v5.5.2 和 Waveshare 开发板引脚复核。接线图与供电细节见 [`应急方案_无PCB/`](应急方案_无PCB/)。

## 信号 ↔ GPIO

| 模块 | 信号 | GPIO |
|---|---|---|
| I²C1 总线（4 个从机，100 kHz，2.2 k 上拉） | SDA / SCL | IO20 / IO21 |
| IMU QMI8658（I²C 0x6A/0x6B） | INT | IO23 |
| 环境光 BH1750（I²C 0x23）、电流 INA219（I²C 0x40）、电量 MAX17048（I²C 0x36） | — | I²C1 |
| 电机 M0（TB6612，LEDC 20 kHz） | PWM / IN1 / IN2 | IO2 / IO3 / IO4 |
| 电机 M1 | PWM / IN1 / IN2 | IO5 / IO24 / IO25 |
| 电机 M2 | PWM / IN1 / IN2 | IO26 / IO27 / IO32 |
| TB6612 STBY（拉低即急停，固件同拉同放） | M0/M1 桥 · M2 桥 | IO51 · IO52 |
| 编码器（PCNT 正交解码，开漏输出需上拉到 3V3） | M0 A/B · M1 A/B · M2 A/B | IO30/31 · IO28/29 · IO46/47 |
| 测试 strap（上电短接 GND 进入 TEST 模式） | — | IO48 |

电机堵转保护依据 INA219 电流和编码器是否转动判断，触发后拉低 STBY。TEST 模式见 [`13_测试模式与上位机_v1.md`](13_测试模式与上位机_v1.md)。

## 开发板边沿引脚（取自 Waveshare ESP32-P4-WIFI6 datasheet 丝印）

- **左排**：`52 51 GND 31 30 29 28 GND 50 49 5 4 GND 3 2 SCL(IO8) SDA(IO7) GND 24 25`
- **右排**：`+VBUS VSYS GND EN 3V3 20 21 GND 22 23 RUN 26 GND 27 32 33 46 GND 47 48`
- **底部 H4（调试）**：`IO9 GND RXD TXD` · **USB**：`V D- D+ G` · **背面焊盘**：`36 34`
- **板载已占用**：IO7/8 = I²C0（与板载 ES8311 共用）、IO9~13/53 = 音频 I²S、IO39~44 = microSD、RXD/TXD = 调试 UART。
- **可用 GPIO 池**：`2 3 4 5 20 21 22 23 24 25 26 27 28 29 30 31 32 33 34 36 46 47 48 49 50 51 52`（+ I²C0 的 IO7/8、H4 的 IO9）。
- ❌ `34/36` 是 strapping 脚（ESP32-P4 strapping = GPIO34/35/36/37/38，IO36 还决定 boot mode），且只在背面焊盘、没有引到 2×20 排针，因此不作备用。

## 复核清单

1. ✅ **strapping**：在用引脚没有落在 strapping 脚上。
2. ✅ **ADC**：ADC1 = IO16–23，ADC2 = IO49–54。当前电流采样走 INA219（I²C），不占 ADC。
3. ✅ **外设容量**：P4 经 HP GPIO 矩阵，PWM / 编码器 / I²C 可以落在任意引出脚；ESP-IDF v5.5.2 `soc_caps` 中 PCNT 有 4 个单元（三路编码器够用）、LEDC 8 通道、I²C 2 HP + 1 LP。
4. ✅ **引出且空闲**：在用引脚都在 Waveshare 2×20 排针上，不与板载 ES8311、microSD、I²S、MIPI、C6、USB 冲突。
5. ⚠️ **IO24/IO25（M1_IN1/IN2）是 USB-Serial-JTAG 默认引脚**：用作 GPIO 会关闭片上 JTAG（可以接受），并且复位时为浮空，因此上电时由固件先拉低 STBY，保证电机关断。

> 源：ESP32-P4 Datasheet v1.3（Table 2-7 模拟功能 / Table 3-1、3-3 strapping）、ESP-IDF v5.5.2 `soc_caps.h`、Waveshare ESP32-P4-WIFI6 datasheet。

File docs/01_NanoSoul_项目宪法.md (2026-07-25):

# NanoSoul 核心设计决策

> 本文记录项目范围、技术路线和选型依据。

---

## 1. 项目本质

NanoSoul 是参加 **2026 第九届全国大学生嵌入式芯片与系统设计竞赛・芯片应用赛道（嵌赛）/ 乐鑫赛道** 的参赛作品。同时具备产品化潜力。

- **比赛官网**：www.socchina.net
- **赛题平台**：乐鑫 ESP32-P4（**乐鑫 2026 年首次加入嵌赛，无往届乐鑫获奖样本可循**）
- **主控指定**：ESP32-P4 或 ESP32-S3 二选一；选题一/二/三推荐 P4
- **主报选题**：**选题一（嵌入式边缘AI应用，P4）**，文档说明同时覆盖选题二（人机交互）、选题三（运动控制）
- **赛题要求（原文）**：作品主要功能代码必须运行在乐鑫芯片上。若仅用作通信或简单 IO 控制，主要功能由第三方芯片实现，将被视为违规选题。
- **验证方式**：现场断网运行视觉、状态判断、表情和运动控制，证明主要功能由 P4 承担。

## 2. 一句话定位

> **NanoSoul 是一台基于 ESP32-P4 的桌面陪伴机器人。它在本地检测人脸和环境状态，据此调整表情与运动；联网后通过云端服务完成语音对话。**

## 3. 开发方式

> 视觉、语音、表情、摄像头和联网优先采用乐鑫官方组件，自研工作集中在状态机、运动控制和整机测试。所有关键设计和自动生成内容均经过人工复核。

## 4. 核心架构原则

### 4.1 P4 承担本地处理
- 视觉处理、状态判断和运动控制在 ESP32-P4 上运行
- 云端服务只处理语音识别、对话和语音合成，不参与实时运动判断

### 4.2 硬件可靠性分层（2026-07 修订，随去悬崖决策与 IMU 换型同步）
- **Layer 1（碰撞/抬起）**：IMU **QMI8658**（顶替 ICM-42688-P，选型证据链见 06），片上 Tap / Wake-on-Motion 事件出中断
- **Layer 2（视觉感知）**：OV5647 MIPI-CSI 相机 + 本地 ESP-DL 推理
- **已砍掉**：多区 ToF（VL53L5CX）——速度慢不需要；**悬崖 IR（ITR20001×3）**——本版去掉，lift/碰撞由 IMU 兜底，桌沿风险靠低速运动约束
- 另有硬需求：**电机堵转过流保护**（电流采样 + 编码器不动 → STBY 急停）

### 4.3 复用优先
- 视觉/语音/表情/对话/摄像头/联网优先用乐鑫官方且已支持 P4 的成熟组件
- 可由工具生成的初稿需经过人工复核
- 自研工作集中在没有合适现成组件的部分，如本地状态机

### 4.4 双形态规划
- **V1（比赛 + 首发）**：一体式桌面机器人
- **V2（产品迭代）**："基座 + 取下挂坠"模式
- **V1 阶段不实现 V2**，外形上预留磁吸暗示

### 4.5 工具调用架构（混合方案）
- **本地工具**（必须本地，比赛加分）：运动、表情、传感器查询、本地视觉
- **局域网工具**：直调 Home Assistant REST API
- **互联网工具**（demo 用）：发邮件、查天气
- **MCP / MQTT broker / Apple 日历**：**比赛阶段不上**

## 5. 必须坚守的反面清单

| 不做 | 理由 |
|---|---|
| 纯云端 LLM 方案 | 违反"主要功能在 P4" |
| 全本地小模型 | 体验上不去 |
| 外挂安卓/树莓派副屏 | 桌面机器人不叠 SBC |
| ESP32 上做 CalDAV | 复杂度高无加分 |
| ESP32 上跑完整 MCP client | 协议层太重 |
| 毛绒外套带异形屏孔 | 视觉冲突，工程难 |
| 真做"取下挂坠"形态 | V1 工程量翻倍 |
| Arduino-ESP32 框架 | P4 完整 API 只有 ESP-IDF |
| **为"自己写"重写官方已有且支持 P4 的现成件** | **重复造轮子，浪费完成度** |

## 6. 设计依据（市场/学术）

### 6.1 婴儿图式（Kindchenschema）
所有"萌"的设计遵循 Konrad Lorenz 1943 年婴儿图式七要素，按重要性：
1. 大、深陷的眼睛 2. 圆润的身体形状 3. 厚、大的头 4. 鼓起的前额 5. 圆鼓的脸颊 6. 短粗的四肢 7. 柔软的表面

**关键反规律**：拟人化（humanoid）会降低婴儿图式效果。NanoSoul 走"小生物形"，不走"小人形"。

### 6.2 市场参考产品销量
| 产品 | 形态 | 销量 | 价格 |
|---|---|---|---|
| Loona Petbot | 四足机器狗 | 近 10 万台 | $400+ |
| Eilik | 桌面机器小人 | 6 万+ | $139-149 |
| Ropet | 椭圆毛绒萌宠 | 2 万台 | $299 |
| Eiliko | 70g 挂坠 | Kickstarter 3800% | - |
| LOVOT（反面教材） | 圆胖 | 销量平平 | 6 万元 |

### 6.3 外形参数（目标）
- 头:身比 ≈ 1.3 : 1；高度 15-20cm，直径 10-13cm，重量 500-900g
- 屏占脸面积 ≥ 50%；主色白/米白 + 一个 accent
- 1-2 处磁吸配件位；屏向上倾斜 10-15°；摄像头藏在屏上方边框

## 7. 评审应答准备

### 7.1 必答：为什么用 P4 不用 S3？
| P4 能力 | S3 做不到 | NanoSoul 用法 |
|---|---|---|
| MIPI-DSI 2-lane×1.5Gbps + PPA + 2D-DMA | S3 只能 SPI/RGB，无 GPU | 大屏表情流畅渲染 |
| MIPI-CSI 摄像头 + ISP | S3 只有 DVP | **本地视觉感知主人（核心差异化）** |
| H.264 硬件编码 | S3 没有 | 实时视频流（esp_h264，1080P>30fps） |
| RISC-V 双核 400MHz + AI 指令 + FPU | S3 双核 240MHz | **本地小模型推理（esp-detection >18FPS@P4）** |
| 55 GPIO + 丰富 PWM | S3 45 GPIO | 三电机 + 多传感器同时跑 |
| USB 2.0 HS 480Mbps | S3 是 USB FS | UVC 摄像头/海量外设 |

### 7.2 必答：为什么必须有全向移动？
答：主动陪伴需要主动接近，桌面环境只有全向轮能在杂物间游走、贴近主人。这把全向移动从"装饰"变成了"功能本质"。

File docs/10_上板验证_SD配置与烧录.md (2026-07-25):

# 10 · 上板验证：SD 配置 + 烧录 + 读自检

> 本文说明 SD 卡配置、固件烧录和自检结果判读。整机固件已通过板外编译，并完成首轮实物验证（见 §6）。

## 0. 硬件前提

- Waveshare **ESP32-P4-WIFI6** 开发板 + **MIPI-DSI 屏**（ST7701 480×640）+ **OV5647 相机**（MIPI-CSI）插好。
- **microSD 卡**插入板载卡槽（存配置 + 语音临时文件）。
- 电机/编码器/INA219/IMU/BH1750 **本版不接**（固件探测缺席自动降级，不影响启动）。
- 供电：开发板 USB 供电即可（电机不接，无需电池链）。

## 1. SD 卡准备

把 `sdcard_template/nanosoul/config.example.json` 拷到 SD 卡的 `/nanosoul/config.json`，按需填：

- **WiFi**：`wifi.ssid` / `wifi.password`（不填=离线，本地感知照跑）。
- **云端对话**：`chat.provider`（`anthropic` 或 `openai`）+ `base_url` + `api_key` + `model`。
- **语音**（可选）：`stt.*` / `tts.*` 填 OpenAI 兼容端点 + key。
- **上位机**：`companion.token` 改一个自己的口令。
- **运动**：`motion.enabled` 保持 `false`（没接轮）。
- **调试叠加**：`debug.overlay` 保持 `true`（屏上显示硬件/决策参数）。

> **真 key 只在 SD 卡上，不进仓库。**

## 2. 选启动模式并烧录

三种模式（`idf.py menuconfig` → NanoSoul → Boot mode，或改 sdkconfig）：

| 模式 | 用途 |
|---|---|
| `FACE`（默认） | 产品/演示：表情脸 + debug HUD + 全栈跑 |
| `SELFTEST` | **首次上板选这个**：全栈起来后跑自检循环，串口逐项 JSON |
| `TESTPANEL` | 旧三电机 LVGL 测试面板 |

```fish
source /home/gxxl/.espressif/v5.5.2/esp-idf/export.fish
idf.py menuconfig      # 选 SELFTEST（首次）
idf.py -p /dev/ttyACM0 flash monitor
```

`idf.py flash` 会一并写：app + emote 合包(emote_gen) + 人脸模型(human_face_det)。**16MB flash、分区表已重排，首刷会全擦**——确认卡上配置已备好再刷。

## 3. 读自检日志（SELFTEST 模式）

串口每轮每项输出一行 JSON，直接 grep：

```
{"st":"selftest","round":3,"item":"sd_mount","result":"PASS","pass":true,"manual":false,"detail":"..MB free"}
{"st":"selftest","round":3,"item":"camera_stream","result":"PASS",...,"detail":"+15 frames/round"}
{"st":"selftest","round":3,"item":"face_detect","result":"PASS",...,"detail":"6.1fps face=1 a0.09 fr0.71"}
...
{"st":"selftest_round","round":3,"fails":0,"cumulative_fails":0}
```

**判读**：
- `PASS` = 该项好；`SKIP` = 硬件缺席/未配置（**不算失败**，如没接电机的 `mic_record` 之外、没填 key 的 `llm_ping`）；`FAIL` = 要处理。
- 各阶段应绿的项（**共 28 项**，交互功能落地后新增 9 项）：
  - 底座 `sd_mount / config_parse / psram / partition_layout`；表情 `emote_mount / emote_render / hud_draw`；相机+人脸 `i2c0_probe / camera_stream / face_detect`。
  - **交互纯逻辑（恒绿，无硬件）**：`motion_ik / arbiter_sim / soul_sim / expr_sim / fusion_sim / imu_sim / prim_sim / stall_sim`——仲裁器/状态机/表情防抖/PC 融合/IMU 检测/运动原语/堵转 FSM 的逐条断言。
  - **交互传感探针**：`light_read`（BH1750）/ `imu_probe`（QMI8658 0x6A/0x6B）/ `touch_probe`（FT6x36 0x38）——接线则 PASS，未接 SKIP。
  - 联网 `wifi_connect / sntp / llm_ping`（无配置 SKIP）；音频 `codec_playback / mic_record`；上位机 `ws_loopback`。
- `wakenet_load` 现为真检测：MultiNet/WakeNet 构建下报引擎名（如 `multinet(小王小王)`）PASS；模型分区未烧 / 初始化失败报 FAIL；能量 VAD 构建报 SKIP。

建议保存连续几轮 selftest JSON，尤其是所有 `FAIL` 项，便于比较不同固件版本。

## 4. FACE 模式看什么

- 屏上：表情动画（默认 waiting/张望），顶部 6 行绿字 HUD（SOUL 状态 / FACE bbox / MOT 意图+duty / ENC / NET / FPS / HEAP）。
- 人走进相机视野：HUD 的 `FACE p1 x.. a.. f..` 跳动；由远及近 SOUL 依次 APPROACH→ENGAGE→RETREAT；正脸盯 1.5s→GAZED，表情切 `o`。**全程可断网**。
- 联网后：默认 VAD 模式下，近距离说「小王小王 + 问题」后开始录音；云端 STT 文本确认含“小王”时播放提示音并进入对话/TTS。应答后 8s 内可直接续聊。MultiNet 和 WakeNet 是实验选项，当前不作为演示方案。
- 电脑连 `ws://nanosoul.local/ws?token=<你的token>`（浏览器控制台/websocat）：收到 1Hz `state` + 即时 `event` 流；发 `{"type":"ask","id":1,"text":"你好"}` 收到回复；发 `{"type":"estop"}` 进 FAULT。

## 5. 已知待办（上板后按需迭代）

- **相机方向**：屏物理旋转装法若上下/镜像反了，改 `components/face` 的 `FACE_ROTATE_CCW`（编译参数），半小时内可对好。
- **麦克风录音路径**：本板首次验证；`mic_record` 若 `rms≈0` 说明 ADC/AFE 增益或时钟要调（`components/audio` 的 `esp_codec_dev_set_in_gain` / mclk）。
- **C6 WiFi**：esp_hosted 用默认 SDIO 配置；`wifi_connect` 一直 SKIP/连不上则可能要按 Waveshare 板配 SDIO 引脚。
- **接电机时**：M1 的 IN1/IN2 占 IO24/25（=USB 串口），接线前要在 `BOARD_MAPPING` 里挪 M1 或改用 WS 遥测代替串口日志；然后 SD 配置 `motion.enabled=true` 才真转轮。
- **语音触发方式**：默认选择能量 VAD + STT 文本门（`CONFIG_NS_WAKE_WORD_VAD`）。`menuconfig → NanoSoul → Voice wake-word detector` 可切换到 MultiNet 或 WakeNet 实验路径。双模型仍随构建写入 `model` 分区。2026-07-24 的实物测试中，VAD 对话链连续运行 120s，未出现 panic、WDT 或 reset；MultiNet/WakeNet 的模型和 AFE 管线可以运行，但口令检测尚未稳定。

## 6. bring-up 实测记录（2026-07-05，v1.3 硅版，commit `baf909d`）

首轮上板结果：**13 PASS / 4 SKIP / 1 FAIL**。

- **PASS**：底座 4 项（`sd_mount/config_parse/psram/partition_layout`）、表情 3 项（`emote_mount/emote_render/hud_draw`，渲染 30fps）、相机与人脸（`i2c0_probe/camera_stream/face_detect`——OV5647 检出、800×1280 采集、检测 **8fps**）、决策纯逻辑（`motion_ik/soul_sim`）、`codec_playback`、`ws_loopback`。
- **SKIP**：`wifi_connect / sntp / llm_ping`（SD 未配 WiFi/key）、`wakenet_load`（MANUAL，本版能量 VAD）。
- **FAIL**：`mic_record` —— ES8311 ADC 静音（即 §5 第 2 条首验风险项，待查）。

断网状态下本地感知闭环（看到人 → 表情/运动意图响应）完整跑通。上板踩坑与修复已全部固化进 `sdkconfig.defaults` / 代码，复刷不会复现：

| 症状 | 根因 → 修复 |
|---|---|
| 开机断言循环 `mempool no mem` | esp_hosted SDIO mempool 抢内部 RAM → `CONFIG_ESP_HOSTED_MEMPOOL_PREFER_SPIRAM=y` |
| 无 WiFi 配置时 companion 起不来 | tcpip 栈未起 → `esp_netif_init()` 无条件早调 |
| `/dev/video0` 不注册 | 传感器驱动未编入 → `CONFIG_CAMERA_OV5647=y` |
| `ppa_do_scale` INVALID_ARG、帧全丢 | PPA 输出缓冲未按 cache line 对齐 → 128B 对齐分配 |
| HUD 刷屏 `no mem for mask_buf` | gfx label 未设尺寸（mask_buf=w×h）→ `gfx_obj_set_size` |
| 渲染帧计数恒 0 | `ALL_FRAME_DONE` 不触发 → 改 `ONE_FRAME_DONE` |
| 内部 RAM 吃紧 | emote 绘制缓冲移 PSRAM + `SPIRAM_MALLOC_ALWAYSINTERNAL=4096` |

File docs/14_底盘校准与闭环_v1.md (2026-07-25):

# 14 · 底盘校准与轮速闭环 v1

> **文档性质：校准与开发记录。当前样机的验证状态以 README 和 docs/00 为准。**
>
> 三全向轮（GA12-N20 118:1 + Ø~70mm 全向轮，120° 一后两前）从「开环 duty」升级为
> 「每轮转速闭环 + 里程计」的设计与校准记录。协议基线见 docs/13；轮角/引脚真值见
> `components/motion/motion.c` 与 `docs/BOARD_MAPPING.md`。

## 1. 架构

```
意图 (vx,vy,wz ~[-1,1])
  → motion_ik()          纯 IK + 峰值归一化（components/motion/motion.c，不变）
  → apply 桥 ±1023        闭环开: wheel_ctrl_apply()   闭环关: app_face_motor_apply()
  → app_wheelctrl 50Hz    sp = cmd/1023 × rpm_max（电机轴 rpm）
       每拍: 自差分 encoder_count → 瞬时 rpm → EMA(0.4)
             设定值斜坡(move.ramp_ms 满量程) → 死区(sp_deadband_pct)
             duty = ks·sign(sp) + kv·sp + PI(sp−meas)   ← espressif/pid_ctrl
       同拍: odom_step() 里程计积分 (x,y,θ) → telemetry
  → motor_set()
```

- **前馈担主力，PI 只修残差**：kS（静摩擦死区）/kV（斜率）来自 A2 扫描；积分对输出的
  贡献限幅 ±120 duty（`WC_TRIM_I_MAX`，≈满速 12% 修正权限）。夹太松会在斜坡期灌满
  积分导致大超调（pid_ctrl 的 `max_integral` 夹的是误差累计和 rpm·拍，刻度=上限/ki）。
- **反馈不走 `encoder_rpm()`**（100ms 窗+EMA 滞后太大），控制环内 50Hz 自差分。
  分辨率：满速 ~150 计数/拍；10% 速度 ~15 计数/拍（±7% 量化，EMA+PI 抹平）。
- **驱动权单一**：motor_test / wheel_sp 抢权统一走 `motion_set_apply(NULL)` +
  `wheel_ctrl_halt()`，归还走 `app_face_motor_bridge()`（自动选闭环/开环桥）。
- **急停链不变**：堵转 FSM（app_sense.c）拉 STBY 时 wheelctrl 冻结并清积分，
  恢复后干净起步。闭环顶着堵转把 duty 拉高反而让「大 duty + 零速 + 大电流」判据
  更快触发。
- **开环回退**：`motion.calib.closed_loop=false` → 原始 duty 直通（改配置重启即回）。
  此时 wheelctrl 仍以测量模式跑（只算里程计，不碰电机）。
- **里程计**（components/motion/odom.c，纯函数）：FK 是 motion_ik 的解析逆，
  `vᵢ = Δ计数/3304 × π·wheel_d`，中点航向积分。口径=cm 级位移预算
  （docs/12 approach_budget_cm），辊子打滑 ±8% 级误差，不做全局定位。

## 2. 配置（config.json `motion.calib`，代码默认值兜底）

| 字段 | 默认 | 说明 |
|---|---|---|
| `closed_loop` | false | 闭环开关；**A2/A3 校准回填后才翻 true** |
| `wheel_d_mm` | 70.0 | 有效轮径；A3 直线滚动实测修正 |
| `body_r_mm` | 56.0 | 轮心到中心距；CAD 占位，A3 自旋实测修正 |
| `rpm_max` | 15000 | 电机轴满指令转速（三轮满 duty 实测最小值 ×0.95） |
| `ks[3]` | 0,0,0 | 每轮静摩擦前馈（duty），A2 拟合 |
| `kv[3]` | 0.0682×3 | 每轮速度前馈（duty/rpm），A2 拟合；默认=1023/15000 名义值 |
| `pid` | kp .05 / ki .02 / kd 0 | 每拍口径；一阶模型仿真 稳定~260ms/超调~15% |
| `sp_deadband_pct` | 3.0 | 设定值死区（% rpm_max），防零点抖鸣 |

## 3. 协议增量（docs/13 风格，前向兼容）

命令（仅 TEST 模式；FAULT 拒绝；参数夹限）：

```json
{"type":"wheel_sp","sp":[3000,3000,3000],"ms":1500}   // 闭环阶跃（PID 整定）
{"type":"pid_set","kp":0.05,"ki":0.02,"kd":0}          // 在线改增益（不落盘）
{"type":"odom_reset"}                                   // 里程计清零
```

sense 帧新增字段：`"sp":[rpm×3]`（斜坡后设定值，开环恒 0）、
`"odom":[x_mm,y_mm,th_rad]`。hwinfo `range` 新增 `closed_loop/wheel_d_mm/body_r_mm/rpm_max`
（生效中的配置）。

板上 sim 自检（SELFTEST 模式，纯逻辑）：`fk_roundtrip`（ik→fk 互逆）、
`odom_sim`（方形闭合+整圈）、`wheelctrl_sim`（收敛/堵转/重启/死区）。

## 4. 校准 runbook（顺序：方向 → 前馈 → PID → 几何）

通道：**companion WS**（电机占 IO24/25 后 USJ 不可用）；日志 UART0/CH343。
Claude 驱动命令与采数，Captain 做物理操作。

### A1 方向/映射（架起，轮悬空 → 落地验收）
1. 逐轮 `motor_test m=i duty=+460 ms=800`，记录：是哪个物理轮（后/左前/右前）、
   俯视转向、`enc` 计数符号。
2. 对照 `motion.c` 轮角约定（+x 前、0°=后轮?——以实车为准）修 `MOTION_WHEEL_ANGLE_DEG`
   的 M0/M1/M2 分配与符号 → rebuild → reflash。
3. 落地 teleop 验收：`wz>0` 逆时针自旋、`vx>0` 前进、`vy>0` 左横移。三项方向全对才过。

### A2 前馈扫描（架起，电池供电）
```
python3 tools/testhost/calib_sweep.py --ws <ip> --token <token>
```
逐轮双向 ±15..100% duty 阶梯 → 拟合每轮 kS/kV + 满 duty 转速 → 按脚本输出回填
`ns_config.c` 默认值与 SD config（`rpm_max` 取三轮最小 ×0.95）。双向不对称 >10% 要留意
（接线/机械偏磨）。

### PID 整定（架起；改 SD `closed_loop:true` 或直接改默认值重刷）
1. `sense_rate hz=50`，`wheel_sp sp=[0.3,0.3,0.3]×rpm_max ms=2000` 起步，观察 sense
   的 `sp` vs `enc.rpm`。
2. 阶跃 30%→60%：`pid_set` 在线调。验收：稳定 <300ms、超调 <20%、低速（10%）无振荡。
3. 三轮一致性：同设定值下三轮稳态 rpm 差 <3%。

### A3 几何（地面）
1. **直线**：`odom_reset` → teleop `vx` 慢速走到 odom x=500mm 停 → 卷尺量实际
   → `wheel_d_mm ×= 实测/500`。往返各一次取平均。
2. **自旋**：`odom_reset` → `wz` 慢速转到 odom θ=6π（3 圈）→ Captain 数实际圈数
   （胶带贴地做记号）→ `body_r_mm ×= 3/实际圈数`。
3. 回填 → 复测一轮。

### 总验收
- 1m 前进 / 1m 横移 / 360° 自旋，odom vs 卷尺/记号误差 <8%。
- 堵转：手按住一轮 1s → FAULT 急停（事件 `stall`）→ 松手清障恢复。
- SELFTEST 模式全绿（新增三项 sim 在列）。

## 5. 实测记录（校准会话回填）

| 项 | M0 | M1 | M2 | 备注 |
|---|---|---|---|---|
| 物理位置/轮角 | ⬜ | ⬜ | ⬜ | A1 |
| kS (duty) | ⬜ | ⬜ | ⬜ | A2 |
| kV (duty/rpm) | ⬜ | ⬜ | ⬜ | A2 |
| 满 duty 转速 (rpm) | ⬜ | ⬜ | ⬜ | A2，电池供电 |
| PID 终值 | ⬜ kp/ki/kd | | | 整定 |
| wheel_d_mm 有效值 | ⬜ | | | A3 直线 |
| body_r_mm 有效值 | ⬜ | | | A3 自旋 |
| 总验收误差 | ⬜ | | | <8% 过 |

## 6. 已知风险与口径

- 低速端（<10% rpm_max）编码器量化明显，靠 EMA+死区；巡航段无碍。
- USB 供电与电池供电 kV 有偏差——**校准以电池为准**，残差 PI 吸收。
- kv 标定偏差 >12% 时积分权限（±120 duty）不够补满速段余差——重跑 A2 而不是放松
  `WC_TRIM_I_MAX`。
- 里程计误差口径 ±8%（辊子打滑+有效轮径波动），只用于短程位移预算。
- `pid_set`/`wheel_sp` 都不落盘；定稿参数进 `ns_config.c` 默认值 + SD 模板。

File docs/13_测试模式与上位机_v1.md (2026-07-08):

# 13 · 测试模式与测试上位机 v1

> 目的：在**真机**上系统化测试所有硬件/传感器的信息范围，并能从上位机**覆盖/注入**传感数值去驱动核心代码（soul 状态机、堵转保护、事件反应），实时观察机器人反应。
>
> 本文是**测试扩展协议的真值源**。它对 [`09_上位机接口协议_v1.md`](09_上位机接口协议_v1.md) 做**加法演进**（新 `type` 旧端忽略、字段只增不改语义——docs/09 前向兼容铁律）。固件实现见 `components/testlink/`、`components/simsense/`、`main/app_testmode.c`；上位机见 `tools/testhost/index.html`。
>
> 不做 PC 端设备模拟器——测试对象就是接好的真机。

## 1. 进入测试模式

- **硬件跳线**：上电时把 **IO48 短接到 GND** → 进 TEST 模式（内部上拉，采样去抖后释放该脚；开路 = 正常 FACE）。IO48 在开发板右排边沿最后一脚。冲突时 fallback = IO33（改 `main/nanosoul_main.c` 的 `TEST_STRAP_GPIO` 一处）。
- **板外无跳线**：`idf.py menuconfig` → NanoSoul → Boot mode → **Test mode**（`CONFIG_NANOSOUL_MODE_TEST`）强制进入，供无实物构建/联调。
- strap **优先于** Kconfig。

TEST 模式 = 完整 FACE 运行时（soul 照常跑、companion WS 起、所有传感器在线）+ 测试服务：传感覆盖注入、`motor_test`、USB-Serial-JTAG NDJSON 通道、强制连接信息 HUD、屏幕**长按 = 急停**。

**关键设计**：覆盖值在各传感生产者边界注入，走**正常全链路**（真实检测器 → 事件总线 → soul → telemetry → 表情/电机）。测的是真核心代码对刺激的真实反应，不是旁路仿真。

## 2. 连接上位机

打开 `tools/testhost/index.html`（纯浏览器单页，零安装零 CDN），两种通道任选：

- **WebSocket**：`ws://nanosoul.local/ws?token=<companion.token>`（或填 IP）。开发板联网后 HUD 屏上会显示 IP。连接建立即收到一帧 `hwinfo`。
- **WebSerial**（**仅 Chromium 系** Chrome/Edge）：USB-Serial-JTAG，115200，NDJSON（一行一 JSON）。**Wi-Fi 不通也能测**。上位机按行首 `{` 区分协议与日志，非 JSON 行进日志窗。

> 串口占用说明：TEST 模式把 USB-Serial-JTAG 用作协议通道，故固件 `CONFIG_ESP_CONSOLE_SECONDARY_NONE`——**日志改走 UART0**。持板者若习惯经 USJ 看 log 会受影响；flash 走下载模式不受影响。

## 3. 协议加法（机器人 → 上位机）

信封同 docs/09：`{"v":1,"type":"<kind>","ts":<开机ms>,...}`。

### `hwinfo`（连接时推 + 响应 `hwinfo_get`）
```json
{"v":1,"type":"hwinfo","ts":123,
 "fw":{"ver":"...","idf":"v5.5.2","mode":"TEST"},
 "i2c1":{"pins":"SDA=20,SCL=21","scan":[35,64,106],
   "expect":[{"addr":106,"name":"QMI8658","present":true,"note":"..."},
             {"addr":35,"name":"BH1750","present":true},
             {"addr":64,"name":"INA219","present":true},
             {"addr":54,"name":"MAX17048","present":true,"note":"固件未接入"}]},
 "i2c0":{"pins":"SDA=7,SCL=8","scan":[24,54,56]},
 "pins":{"motors":[{"m":0,"pwm":2,"in1":3,"in2":4,"enc_a":30,"enc_b":31,"stby":51},...],
   "imu_int":23,"strap_test":48},
 "range":{"lux":[1,65535],"accel_g":4,"current_a_fs":3.2,
   "enc_cpr_motor":28,"gear":118,"duty_max":1023,"stall_ma":400}}
```
`present` 由现场 I²C 探测决定（`scan` 为 0x08–0x77 全扫结果）。

### `sense`（默认关，`sense_rate` 开，10–50Hz；snprintf 组帧）
```json
{"v":1,"type":"sense","ts":123,"seq":42,
 "accel":[0.02,-0.01,9.81],"gyro":null,"lux":312.5,"cur_ma":85,
 "enc":[[1234,55.2],[..],[..]],"duty":[0,-102,102],
 "lifted":false,"tilted":false,"ovr":5}
```
`enc[i]` = `[计数, 电机轴 rpm]`；`ovr` = 覆盖激活位图（bit i = 通道 i，见 §5）。`gyro` 当前恒 `null`（驱动只读 accel）。

### `event` 增补
docs/09 事件表之外，补 `selftest_item`：`{"name","result":0|1|2,"detail","round"}`（0=PASS/1=FAIL/2=SKIP）。触发 `selftest` 命令后逐项流出。

## 4. 协议加法（上位机 → 机器人命令）

每条 `{"v":1,"type":"<cmd>","id":<n>,...}`，回 `{"type":"ack","id":<n>,"ok":..,"err":".."}`。

| cmd | 字段 | 动作 |
|---|---|---|
| `hwinfo_get` | `{mode?}` | 回一帧 `hwinfo` |
| `sense_rate` | `{hz:0..50}` | 开/调/关 sense 流；ack 回显 `hz` |
| `override_set` | `{ch, v, ttl_ms}` | 覆盖某通道；`v` 标量或数组（长度须匹配，见 §5）；`ttl_ms=0` 常驻 |
| `override_clear` | `{ch \| "*"}` | 清一个通道或全清 |
| `inject_event` | `{name, text?}` | 直接 post 一个交互事件（见 §6） |
| `motor_test` | `{m:0..2, duty:±1023, ms:100..5000}` | 单电机开环跑一段（到时 coast）；**仅 TEST 模式**、FAULT 态拒绝、参数夹限；执行期摘 motion apply 回调防抢 |
| `motor_stop` | `{}` | 全停 + 拉低 STBY |

沿用 docs/09 既有命令（`ask/set_emotion/teleop/get_snapshot/estop/clear_fault/config_reload/set_overlay/selftest/pc_state`）不变；`selftest` 现真跑一轮（结果走 `selftest_item` 事件流）；`get_snapshot` 仅 WS 通道（串口回 `err:"ws only"`）。

## 5. override 通道（`components/simsense/`）

| ch 名 | 值数 | 含义 | 插桩点 |
|---|---|---|---|
| `lux` | 1 | lx | `light.c` 1Hz → 真实迟滞 → DARK/BRIGHT |
| `accel` | 3 | m/s² (x,y,z) | `imu.c` 100Hz → 真实 tap/lift/tilt 检测器 |
| `gyro` | 3 | dps（预留，当前不消费） | — |
| `current_a` | 1 | A（正=放电） | `app_sense.c` 10Hz；覆盖时强制 `current_present=true` 让堵转判定吃到 |
| `enc_rpm` | 3 | 电机轴 rpm | `app_sense.c` 10Hz（count 不覆盖） |
| `face` | 5 | present,cx,cy,area,frontal | `vision.cpp` `vision_get()`（soul 唯一视觉入口，无摄像头也生效） |

## 6. inject_event 名字表

`tap` / `tap2`(双击) · `lifted` / `placed` · `dark` / `bright` · `touch` / `touch_long` · `loud` · `wheel_moved` · `wake` · `face_present` / `face_lost` / `gazed` · `stall`(带 `text`) / `fault`(带 `text`)。

> `wake` 不只是 post 一个事件——它还 `voice_trigger()`，驱动一次**真实语音回合**（录音 → ASR → chat → TTS → 播放），即 docs/13「注入驱动真实决策路径」。断网 / STT / TTS 失败会有本地兜底提示音，不静默。

## 7. 硬件真值表（无 PCB 模块版；与 hwinfo 帧同源）

| 项 | 真值 |
|---|---|
| I²C1 (SDA=IO20/SCL=IO21, 100kHz) | QMI8658 **0x6A**(备 0x6B, INT=IO23, WHO_AM_I 寄存器 0x00=0x05, ±4g=8192LSB/g) · BH1750 **0x23**(1–65535lx) · INA219 **0x40**(0.1Ω shunt, LSB 10µV, ±3.2A) · MAX17048 **0x36**(在线但固件未接入) |
| I²C0 板载 (IO7/8) | ES8311 **0x18** · FT6x36 触摸 **0x38** · OV5647 SCCB **0x36**(不同总线,不冲突) |
| 电机(LEDC 20kHz, duty≤1023) | M0 PWM=IO2/IN1=IO3/IN2=IO4 · M1 IO5/IO24/IO25 · M2 IO26/IO27/IO32；**STBY 分置 IO51(M0/M1)+IO52(M2)**，同拉同放，低=急停 |
| 编码器(开漏,上拉 3V3) | M0 IO30/IO31 · M1 IO28/IO29 · M2 IO46/IO47；**电机轴 28 计数/圈**(输出轴=×118=3304,仅换算) |
| 堵转判定 | 电流 ≥ `protect.stall_ma`(默认参考 400mA) 且某轮 |duty|>307 且 |rpm|<5 持续 `stall_ms` |
| 测试 strap | **IO48 短接 GND**（fallback IO33） |

## 8. 验证清单

**板外（队友可跑）**：
- `idf.py build` 全绿（FACE 默认 + `CONFIG_NANOSOUL_MODE_TEST` 各一次）。
- SELFTEST 构建下纯逻辑 sim + `override_sim` 全绿。
- 浏览器直接打开 `index.html` 无 console 报错（headless chromium 注入合成帧回归通过）。

**板上（持板者，一次过）**：
1. 跳线 IO48→GND 上电 → HUD 显 TEST + IP；开路 → 正常 FACE。
2. 浏览器连 WS → hwinfo：0x6A/0x23/0x40 全绿（0x36 出现属正常）。
3. 量程实测并导出报告：遮光 <5lx / 手电 >1000lx；翻板六面 accel 各轴 ±9.8；`motor_test` 三轮正反转 rpm 符号正确、空载电流 ~40mA/轮；手拨轮 count 变化。
4. 堵转两法：真堵（手捏轮 + teleop）→ `stall` 事件 + 电机断电；纯注入场景（`current_a=0.6` + `enc_rpm=0` + teleop）→ 同样跳闸——证明保护对**数值**而非物理敏感。
5. 反应链：覆盖 `lux=0` → soul 进 DOZE；`accel` 敲击波形 → 表情反应；inject `lifted` → LIFTED 冻结电机；覆盖 `face` → 离开 IDLE。
6. 拔 Wi-Fi 配置重启 → WebSerial 走通上述 2/3/5。
7. UART0 日志无异常；FACE 模式回归（老命令/表情/自主行为）不受影响。

## 9. 边界

- WebSerial 仅 Chromium 系；其余浏览器走 WS。
- `motor_test` 安全：仅 TEST 模式 + FAULT 拒绝 + 参数夹限 + 执行期摘 motion apply；屏幕长按 ESTOP / `motor_stop` / STBY 拉低多重兜底。
- sense 50Hz×~250B≈12KB/s，WS/USJ 均宽裕。
- token 明文 query 沿用 docs/09（LAN only），测试页不改安全模型。

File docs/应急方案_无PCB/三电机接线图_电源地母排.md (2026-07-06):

# 无 PCB · 三电机接线图（电源/地母排版）

> **为什么有这一版**：实测踩过一次坑——电机一转，带 M0/M1 的那片桥 VM-GND 从 6.1V 塌到 1.3V。
> 查实是**电机回流地没有干线**：只"连到公共地"，但回流被逼着走细线/串接，安培级电流在细线上压降 ~5V → 桥 GND 被顶起 → VM-GND 只剩 1V 多。
> **解法**：用面包板一整排做**又宽又短的地干线（母排）**，所有地汇到它、再粗线回 XL6009 OUT−。本图把这套固化下来，防复现。

## 0. 一句话原则（红线）
**电机的大电流走「母排干线」，不走细线串接；所有地汇到同一条「星地母排」。**

## 1. 拓扑总览（两条母排）

```
电池1S ─B+/B−→ TP4056(保护+充电) ─OUT+→ 开关 ─→ XL6009(升5.9V)
                                                   │OUT+              │OUT−(粗!)
                                                   ▼                  │
                                            INA219(串入测总流)         │
                                                   │Vin−              │
      ＋5.9V 红轨(功率正)                          ▼                  ▼
  ●━━━━━━━━━━━━━━━━━━━━━━━━━━━━━━━●            (接红轨)         GND 蓝轨 ★星地
     │VM            │VM                                       ○━━━━━━━━━━━━━━━━━●
  [TB6612#1]     [TB6612#2]                                     ▲   ▲   ▲   ▲
   M0(A)/M1(B)    M2(A)                                         │   │   │   │
     │GND──────────┘GND   ── 粗回流，就近落蓝轨 ───────────────┘   │   │   │
                                                                   │   │   │
  开发板GND ───────────────────────────────────────────────────────┘   │   │
  编码器GND(蓝)×3 ─────────────────────────────────────────────────────┘   │
  XL6009 OUT− (星地锚点) ───────────────────────────────────────────────────┘

  电脑USB → 开发板(P4)：  3V3 → 两片桥VCC + 编码器VCC(黑)
                         GPIO → PWM/IN1/IN2/STBY + 编码器A/B
```

- **红轨** = +5.9V 电机功率正（XL6009 OUT+ 经 INA219 串入）。
- **蓝轨** = GND ★星地（XL6009 OUT− 为锚点；两片桥 GND、开发板 GND、编码器 GND 全汇这）。
- 开发板由**电脑 USB**单独供电，只往外出 3V3 逻辑 + GPIO；**不**给电机出力。

## 2. 电源链（电池侧）

| 段 | 接法 |
|---|---|
| 电池 1S LiPo | → TP4056 `B+`/`B−`（充电 + DW01 保护） |
| TP4056 `OUT+` | → **开关** → XL6009 `IN+` |
| TP4056 `OUT−` | → XL6009 `IN−` |
| XL6009 | 输出电位器调到 **5.9V**（空载量准） |
| XL6009 `OUT+` | → INA219 `Vin+` |
| INA219 `Vin−` | → **＋5.9V 红轨** |
| XL6009 `OUT−` | → **GND 蓝轨（星地锚点）**，用粗线 |
| INA219 `VCC/GND/SDA/SCL` | → 开发板 `3V3 / 蓝轨 / IO20 / IO21`（测**全部电机总电流**） |

## 3. 两片 TB6612 桥

> VM=功率(红轨) / VCC=逻辑(3V3) **别接反**；GND 落蓝轨**要粗**；多个 GND 焊盘内部同网，接一个即可（接两个更稳）。

**桥 #1 —— 驱 M0(A路) + M1(B路)，STBY=IO51**

| 桥脚 | 接到 | | 桥脚 | 接到 |
|---|---|---|---|---|
| `VM` | 红轨 +5.9V | | `STBY` | 开发板 **IO51**（高=使能/低=急停） |
| `VCC` | 开发板 3V3 | | `PWMA/AIN1/AIN2` | IO2 / IO3 / IO4 → **M0** |
| `GND` | 蓝轨 星地（粗!） | | `AO1/AO2` | M0 电机 红/白 |
| | | | `PWMB/BIN1/BIN2` | IO5 / IO24 / IO25 → **M1** |
| | | | `BO1/BO2` | M1 电机 红/白 |

**桥 #2 —— 驱 M2(A路)，STBY=IO52**

| 桥脚 | 接到 | | 桥脚 | 接到 |
|---|---|---|---|---|
| `VM` | 红轨 +5.9V | | `STBY` | 开发板 **IO52** |
| `VCC` | 开发板 3V3 | | `PWMA/AIN1/AIN2` | IO26 / IO27 / IO32 → **M2** |
| `GND` | 蓝轨 星地（粗!） | | `AO1/AO2` | M2 电机 红/白 |
| | | | B路(`PWMB/BIN*/BO*`) | 空，备用 |

> 两片 STBY 分开接（杜邦不够没并）：固件 `motors_enable()` 同时拉 IO51+IO52。以后有线想并到一个脚也行，改固件即可。

## 4. 电机（HH-N20-3 丝印）

| 线色 | 含义 | 接到 |
|---|---|---|
| 红 | 电机电源+ | TB6612 `AO1`(或 `BO1`) |
| 白 | 电机电源− | TB6612 `AO2`(或 `BO2`) |

> 转向反了 = 红/白对调（或固件里换方向）。M0→#1 AO，M1→#1 BO，M2→#2 AO。

## 5. 编码器（×3，开漏霍尔，内部上拉）

| 线色 | 含义 | 接到 | M0 | M1 | M2 |
|---|---|---|---|---|---|
| 黑 | 编码器 VCC | 开发板 **3V3**（**不**接电机电源！datasheet 硬性） | — | — | — |
| 蓝 | 编码器 GND | 蓝轨 星地 | — | — | — |
| 绿 | 信号 A(C1) | 开发板 GPIO（内部上拉） | IO30 | IO28 | IO46 |
| 黄 | 信号 B(C2) | 开发板 GPIO（内部上拉） | IO31 | IO29 | IO47 |

## 6. 防复现 · 接线红线（重点）

1. **回流走干线**：每片桥 `GND` 用**短粗线/多根并联**就近落到**蓝轨**；蓝轨再**粗线**回 `XL6009 OUT−`。**绝不**让电机电流经信号地/细杜邦绕回。
2. **单点星地**：`XL6009 OUT−`＋两片桥 GND＋开发板 GND＋编码器 GND，全汇到**蓝轨这一条**。共地是硬需求。
3. **VM 同理**：红轨从 `XL6009 OUT+`(经 INA219)来，每片桥 `VM` 短线就近接红轨；**别从另一片桥串接**。
4. **量验（带载，电机转着量）**：`桥GND ↔ XL6009 OUT− ≈ 0V`、`桥 VM-GND ≥ 5.5V`。出现几伏 = 那段干线不行（这次就是 GND 段出 5V）。
5. **面包板母排电流**：单排约 1–2A；三电机同堵 ~1.2A 偏临界。高电流段尽量短、端子插紧；红/蓝各占**一整排**，不够就**上下两排并联**加宽。
6. **编码器地的精细处理**：编码器 GND 也上蓝轨，但尽量从**靠开发板GND/OUT−那一端（安静端）**入轨，别紧挨大电流桥 GND 入点——减少电机电流在轨上的抖动串进编码器参考（否则计数会带噪）。
7. **旁路电容**：每片桥 `VM↔GND` 就近补 **100µF + 0.1µF**，吸 PWM 开关尖峰，进一步稳 VM。

## 7. 上电自检顺序（防烧件）

1. 先不插电机，只接电源链 → 量红轨 ≈5.9V、蓝轨对 OUT− ≈0V。
2. 插一片桥（VM/GND/VCC/STBY），STBY 先低 → 量 VM-GND ≈5.9V 不塌。
3. 接电机、固件逐个轮转 → 带载量 `桥GND↔OUT−≈0`、`VM-GND≥5.5V`、编码器三路各自只在被驱动时跳。
4. 任一步 VM 塌 / GND 出压差 → 立刻断电，回第 6 节查那段干线。

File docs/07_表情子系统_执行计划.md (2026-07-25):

# 07 · 表情子系统执行计划（esp_emote_gen_player 接入）

> **文档性质：开发过程记录。当前实现与状态以 README 和 docs/00 为准。**
>
> **状态（2026-07-05）：已执行完毕。** P0（旋转 flush 显示通路）/ P1（`tools/emote_repack.py` 合包管线）/ P2（接入 soul 状态机）已全部落地并上板实测（emote 渲染 30fps）；P3（PPA 硬旋转 + happy 表情）仍开放。落地与本文的差异：分区表以根目录 `partitions.csv`（docs/08 §3 的 16MB 版）为准，本文 §3.4 旧方案作废；Kconfig 实际为 `NANOSOUL_MODE`（FACE 默认 / SELFTEST / TESTPANEL 三选一），非 §3.2 的 `NANOSOUL_UI`；工作分支为 `soul-app`，非 §6 建议的 `face`。as-built 架构见 docs/00 §2.4。以下正文保留为执行时的计划与查证记录。

> 目标：把 `esp_emote_gen_player/`（乐鑫 espressif2022 表情引擎独立播放器）+ `spiffs_image/` 里的 5 个情绪包，接到当前无 PCB 模块版整机上，成为决策状态机的"表情执行器"。
> 屏幕动态表情复用现成件（Emote）：本组件是 Brookesia AI Expression 底下那套 gfx/emote 引擎的独立用法。

---

## 1. 现状盘点（2026-07-05，均已实际核验）

### 1.1 组件 `esp_emote_gen_player/`（仓库根，本地 vendored v0.0.2）

- 职责：挂载打包工具导出的二进制表情包 → 驱动 `esp_emote_gfx` 播放（片段规划、立即切 `anim_now` / 播完再切 `anim_fade`）。
- 依赖（component manager 拉取）：`espressif2022/esp_emote_gfx ^3.0.0`、`espressif/esp_mmap_assets`、`espressif/cjson`。IDF ≥5.0，我们的 v5.5.2 满足。
- 自带 gfx 运行时（**不是 LVGL**）：自建渲染任务 + flush 回调直连 esp_lcd 面板；另带一个顶部 tip 文本条（PuHui 20 号字体，**编进 app 约 700KB**）。
- `test_apps/` 是完整参考：P4 上 DPI 面板 `esp_lcd_panel_draw_bitmap` 做 flush、`esp_lcd_dpi_panel_register_event_callbacks(on_color_trans_done)` 回调里 `notify_flush_finished`。

### 1.2 素材 `spiffs_image/*.bin`（共 991KB）

每个 bin 都是**独立完整的 MMAP 资源包**（`esp_mmap_assets` 格式，表项 28B、文件名字段 16B），内含 `index.json` + 一个 `.eaf` 动画：

| 包 | 大小 | 帧数 | 时长@10fps | 建议语义 |
|---|---|---|---|---|
| `waiting.bin` | 93KB | 45 | 4.5s | 待机/张望 |
| `o.bin` | 123KB | 60 | 6s | 惊讶（碰撞/抬起/看到人） |
| `sleep.bin` | 159KB | 75 | 7.5s | 睡眠（暗光/久无交互） |
| `think.bin` | 300KB | 135 | 13.5s | 思考（云端对话等待） |
| `sad.bin` | 316KB | 150 | 15s | 难过（堵转急停/低电量/出错） |

EAF 实测：**画布 640×480（横向）**、24bit、JPEG 分块编码（15 块 × 640×32）。`index.json` 均为 `x:0,y:0, loop:[], fps:10`。

### 1.3 屏与固件现状

- 屏：WLK2802MIPI-15P V2（ST7701S，**原生 480 宽 × 640 高竖屏**），1-lane DSI @700Mbps，DPI 25MHz，双帧缓存在 PSRAM。`components/display/src/st7701.c` 已点亮，且已暴露 `st7701_get_panel()` + `st7701_register_color_trans_done_callback()`——正好是播放器需要的两个对接点。
- 外壳（enclosure/DESIGN.md）：史莱姆形"宽 >> 高"，前脸 facet 嵌屏当眼睛 → **屏横装**。素材按 640×480 导出与此一致。
- 当前固件（perfboard 分支）：`nanosoul_main.c` → `display_init()`（ST7701+LVGL）→ `test_app_start()`（三电机/编码器/INA219 轮转测试，LVGL 状态面板）。
- 分区表：A/B OTA（ota_0/1 各 1.5MB）+ storage FAT 640KB，**尚无表情资源分区**；flash 配置 8MB。

### 1.4 已核实的四个坑（决定方案走向）

1. **引擎无 90° 旋转**（只有水平镜像）：DPI 视频模式面板也做不了 swap_xy。640×480 素材上 480×640 竖屏，**必须在 flush 路径旋转**。
2. **`SOURCE_PATH` 不是"目录里散文件"**：`use_fs` 模式 = `fopen()` 单个完整包文件、禁用 mmap、按需 `fread`。5 个单情绪包若走文件系统方案，每次换情绪都要重新 mount（读文件 + 解析），切换有卡顿。
3. **`anim_fade` 会死锁在 gfx 回调里**：`gfx_anim_play_left_to_tail` 阻塞等渲染循环推进，凡持有渲染锁的上下文（触摸/timer 回调）调用即死锁。test_apps 的解法是队列 + 专职切换任务，必须照抄。
4. **文件名字段长度要对齐**：这批包按 16B 名字段打包，`CONFIG_MMAP_FILE_NAME_LENGTH` 必须 =16（test_apps 的预编译包用 32，别照抄它的 sdkconfig）。

---

## 2. 目标与非目标

**目标**

- 屏 = 机器人的脸：5 情绪可靠播放、方向正确、切换不闪不死锁。
- 表情是**纯执行器**：对上只暴露 `face_set_emotion()`，决策逻辑（何时切什么）留在自研决策状态机（soul），不混进来。
- 资产管线可重复：新增情绪 = 放素材 → 跑脚本 → `idf.py build` 出包，不靠手工摆弄二进制。
- 板外纪律不破：所有共享步骤（build、合包）板外可跑；flash/monitor 仍由持板者手动。

**非目标（本计划不做）**

- 不上整套 ESP-Brookesia 框架（后期若上，face 服务可被其 Expression 替换，接口按此预留）。
- 不做触摸交互（模块屏无触摸）。
- 不做 Rive/复杂动画、不改表情引擎内部。

---

## 3. 架构决策

### 3.1 新组件 `components/face`（表情执行器）

```
components/face/
├── include/face.h      # face_init / face_set_emotion(emo, FACE_NOW|FACE_FADE) / face_set_tip(text)
├── src/face.c          # player 初始化、情绪表、切换队列 + worker 任务（防死锁，坑#3）
├── src/face_flush.c    # 旋转 flush 适配：gfx 画布 640×480 → 面板 480×640
└── Kconfig             # UI 模式选择（见 3.2）
```

- `face.c` 复用 `components/display` 的 `st7701_init/get_panel/register_cb`，**不走 lvgl_port**。
- 切换语义：`FACE_NOW`（事件打断，如碰撞→惊讶）/ `FACE_FADE`（软过渡，如待机→睡眠）。worker 任务优先级 5、队列深度 8，满则丢弃并告警。
- gfx 配置基线（照 test_apps P4 参数起步）：`swap=false`、双缓冲、DMA、`buf_pixels = 640×16`、渲染任务 prio 7 / 5KB 栈 / **绑核 1**（电机控制与安全逻辑留核 0）。

### 3.2 与 LVGL 测试面板共存：Kconfig 二选一

emote gfx 与 LVGL 是两套渲染器，不同时占屏。`NANOSOUL_UI` choice：

- `NANOSOUL_UI_TESTPANEL`（默认）：现状不变——LVGL 电机测试面板，perfboard 调试不受影响。
- `NANOSOUL_UI_FACE`：表情模式——不初始化 lvgl_port，`test_app` 的关键状态（堵转告警等）走 tip 文本条。

好处：app 里 LVGL 与 emote gfx + 700KB 字体不同时链进来，1.5MB 的 ota 分区压力减半；两条路互不拖累。

### 3.3 资产：合包 + 专用分区 + mmap（否决文件系统方案）

5 个单情绪包合成**一个** MMAP 包，刷进专用 `emote_gen` 分区，`SOURCE_PARTITION + mmap_enable` 挂载：

- 切情绪 = `anim_now/fade_name`，纯 mmap 指针切换，**零 IO、无卡顿**；文件系统方案（坑 #2）每次切换要 remount，否决。
- MMAP 格式已逆向核验（头 + 28B 表项：name[16] + size + offset），且 `esp_mmap_assets` 自带官方打包脚本 `py_tool/assets_gen.py`，合包工具成本很低。

### 3.4 分区表重排（一次到位，避免二次全擦）

```
# Name,     Type, SubType,  Offset,    Size
nvs,        data, nvs,      0x9000,    0x6000
otadata,    data, ota,      0xf000,    0x2000
phy_init,   data, phy,      0x11000,   0x1000
ota_0,      app,  ota_0,    0x20000,   0x200000   # 1.5M→2M：emote gfx + 字体 ~700K 进 app
ota_1,      app,  ota_1,    0x220000,  0x200000
emote_gen,  data, spiffs,   0x420000,  0x180000   # 表情包 991K + 后续 happy 等余量
storage,    data, fat,      0x5a0000,  0xa0000
```

合计 6.25MB < 8MB，flash 配置不用动。SubType 写 spiffs 只是沿用 test_apps 惯例（mmap_assets 按 label 找分区，不管 subtype）。

### 3.5 情绪 → 状态映射（当前功能定义的落点）

| 情绪 | 触发源（无 PCB 版实际硬件） | 优先级 |
|---|---|---|
| `sad` | INA219 过流 + 编码器不动 → 堵转急停（硬需求）；MAX17048 低电量；致命错误 | **1 安全类**，`FACE_NOW`，急停期间锁定 |
| `o` | QMI8658 Tap（碰撞）/ Wake-on-Motion（抬起）中断；后续：视觉看到人 | 2 事件类，`FACE_NOW`，播完回落 |
| `think` | 云端 LLM 请求进行中 | 3 会话类，`FACE_FADE` |
| `sleep` | BH1750 暗光持续 / 长时间无交互 | 4 情境类，`FACE_FADE` |
| `waiting` | 缺省态 | 5 兜底 |

规则：高优先打断低优先；同级后到覆盖先到；事件类播完自动回落到当前情境态。**这张表由决策状态机持有，face 只吃结果**——状态机是自研核心，映射逻辑不下沉进 face 组件。

已知缺口：情绪矩阵没有正效价高唤醒（happy，"看到主人"必需），列入 P3 补素材。

---

## 4. 分阶段执行

### P0 — 显示通路验证（先证明"能在这块屏上正确播"）

改动最小化，先打穿最长的未知链路（旋转 flush）：

1. 分区表按 3.4 重排；`sdkconfig.defaults` 加 `CONFIG_MMAP_FILE_NAME_LENGTH=16`（坑 #4）。
2. `main/idf_component.yml` 加本地依赖 `esp_emote_gen_player: {path: ../esp_emote_gen_player}`，首次 build 联网拉 esp_emote_gfx 等，`dependencies.lock` 提交锁版本。
3. `components/face` 骨架 + **CPU 旋转 flush**：gfx 报的脏区（640 宽条带，≤640×32）逐条转置 90° 写入 `draw_bitmap` 转置坐标。旋转方向（CW/CCW）做成编译参数，上板对一次。中间缓冲 640×32×2B=40KB 内部 RAM。
   - 量级估算：15 条带 × 10fps × 20K 像素 ≈ 3M 像素/s 转置拷贝，P4 400MHz 双核无压力；P3 再上 PPA。
4. Kconfig `NANOSOUL_UI` 落地，默认 TESTPANEL；FACE 模式下 `nanosoul_main.c` 走 `face_init()`。
5. **上板（Captain 手动）**：`waiting.bin` 原样直刷分区验证：
   ```
   esptool.py write_flash 0x420000 spiffs_image/waiting.bin
   ```
   挂载走 `SOURCE_PARTITION + mmap`，`full_check` 会顺带验证名字段/校验和假设。

**验收**：板外 `idf.py build` 两种 UI 模式都过；板上 waiting 循环播放，方向正确、无错色（验证 swap=false）、无撕裂；日志确认 index 解析出 1 条目。

### P1 — 资产管线（5 包合 1 + 构建集成）

1. `tools/emote_repack.py`：
   - 解包：按已核验格式（28B 表项）拆出各包 `index.json` + `.eaf`；
   - 合并：生成总 `index.json`（name=情绪名，file/fps/loop 原样保留）；
   - 打包：调 `esp_mmap_assets` 官方 `assets_gen.py`（name_len=16）出 `nanosoul_emote.bin`；
   - 自检：合包后重新解析、逐文件字节比对 + 校验和，round-trip 不过即失败退出（板外可测）。
2. 资产真值源迁移：解出的 `.eaf` + 总 `index.json` 入库到 `assets/emote/`；`spiffs_image/` 的 5 个单包退役为原始导出存档（留 git 历史即可）。
3. CMake 挂钩：`spiffs_create_partition_assets(emote_gen ... COPY_PREBUILT_BIN nanosoul_emote.bin FLASH_IN_PROJECT)`，让 `idf.py build` 板外出包、持板者 `idf.py flash` 一次带上。
4. `face.h` API 定稿 + 5 情绪轮播 demo（定时器轮切，now/fade 交替——即 test_apps 用例去掉触摸）。

**验收**：板外 build 直接产出合包且 repack 自检过；板上 5 情绪轮播，`fade` 无死锁（长跑 ≥30min）、`now` 打断即切。

### P2 — 接入功能状态：表情成为整机反馈面

前置：P0/P1 完成；与决策状态机（自研核心，另行推进）以 3.5 的接口约定对齐。

1. 按 3.5 优先级表实现回落逻辑（face 侧只提供"播完回调/当前态查询"，仲裁在状态机侧）。
2. 现有硬件事件先接三条最有演示价值的：
   - 堵转保护触发 → `sad` + tip 显示告警（复用 test_app 的 INA219+编码器判定）；
   - QMI8658 Tap/WoM → `o`（IMU 驱动就绪后）；
   - BH1750 暗光 → `sleep`。
3. FACE 模式下 test_app 的电机测试改为 tip 文本输出关键行（保持单板调试能力）。

**验收**：断网状态下，拍一下 → 惊讶、捂住光感 → 入睡、堵转 → 难过+急停，全本地闭环（这正是比赛"断网演示"的素材）。

### P3 — 优化与补素材（非阻塞，按需排期）

1. **PPA 硬件旋转**替换 CPU 转置（`esp_driver_ppa` SRM 90°，可直写 DPI 帧缓存），实测 CPU 占用/帧率后决定是否保留 CPU 路径为回退。
2. **补 happy** 及其他情绪矩阵缺口：官方 Emote Pack.zip 素材 → Packer NEXT 按 **640×480** 导出 → repack 管线自动进包。
3. BH1750 → 屏亮度联动（需先确认模块背光控制线是否可接；当前屏不占 GPIO、背光常亮）。
4. OTA 演练：确认 app 升级不动 `emote_gen` 分区；资产版本号写进合包 index 备查。

---

## 5. 风险清单

| 风险 | 概率 | 缓解 |
|---|---|---|
| 旋转方向/坐标映射一次对不准 | 高（必踩） | 做成编译参数，上板半小时内可翻转重试；P0 就验 |
| app 超 2MB（gfx+字体+驱动） | 低 | 已扩到 2MB；仍超则裁 tip 字体（PuHui 700KB 可换小字库或去掉） |
| `assets_gen.py` 输出与手解格式有出入 | 低 | repack 自检 round-trip，板外即可暴露 |
| fps 语义（json 的 10fps 被解析忽略，实际节奏由引擎/EAF 定） | 中 | P0 上板目测节奏；不对则在 face 层用 segment fps 显式指定 |
| esp_emote_gfx 注册表版本漂移 | 低 | `dependencies.lock` 提交；player 本地 vendored |
| 外壳最终改竖装 | 低 | 素材重导 480×640 + 删旋转层即可，两处解耦 |

---

## 6. 纪律与协作约定

- **板外必过**：每步 commit 前 `idf.py build`（两种 UI 模式都编）；repack 自检进共享脚本。flash/monitor/上板验收 = Captain 手动，不进共享任务。
- **分支**：perfboard 分支上还有未提交的电机驱动改动，表情工作从 main 另开分支（建议 `face`），P0 分区表改动会导致下次烧录全擦——和 Captain 的上板窗口对齐后再合。
- **文档同步**：分区表/引脚无新增 GPIO（屏不占 GPIO），`BOARD_MAPPING.md` 不用动；本文件即表情子系统的执行真值，偏差回写这里。

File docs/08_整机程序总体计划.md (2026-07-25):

# NanoSoul 整机程序总体计划 v1

> **文档性质：开发过程记录，不用于描述当前版本。当前实现与状态以 README 和 docs/00 为准。**
>
> **状态（2026-07-05）：本计划已全部执行完毕。** Phase 0–F 逐阶段交付（commits `1878f24` → `69f89b8`），并完成首轮上板 bring-up（`baf909d`，v1.3 硅版：自检 13 PASS / 4 SKIP / 1 FAIL，人脸检测 8fps，断网本地闭环跑通，实测记录见 docs/10 §6）。实现与本计划的主要差异：§2 的模块清单落地时进一步拆分——上位机 WS 独立成 `companion`（不在 netlink）、录放独立成 `audio`、相机采集独立成 `camera`、另增 `dialog` / `bsp` / `board_i2c0`；唤醒当前为能量 VAD（WakeNet 升级路径已留 srmodel 分区）。**as-built 架构真值见 docs/00 §2–§3**。以下正文保留为执行时的计划与已核实事实存档。

> 执行前必读：本计划的每一条"已核实事实"都是本轮实际查证/实测过的，**不要凭训练记忆推翻**。参考实现在 `/home/gxxl/testP4/`（同一块板上大多验证通过）和本仓库 `esp_emote_gen_player/test_apps/`。表情子系统已有独立计划 `docs/07_表情子系统_执行计划.md`（本计划的 Phase A 就是它，细节以它为准）。

## 0. Context

NanoSoul = ESP32-P4 桌面陪伴机器人（嵌赛/乐鑫赛道）。当前仓库固件只有：ST7701 屏 + LVGL 电机测试面板 + 三电机/编码器/INA219 驱动（perfboard 分支，未提交的三电机化改动）。本计划把它扩成**完整整机程序**：

- 本地人脸检测（ESP-WHO/esp-dl，断网本地感知）
- 决策闭环：距离带靠近/退后 + 近距正脸持续→"被注视"→退后；行为触发表情变化
- 表情脸（emote 引擎，docs/07）+ **debug 版本默认在屏上叠加硬件参数**（电机输出、编码器、电流、帧率、状态机状态等）
- SD 卡存用户配置（WiFi、LLM 端点/key、行为阈值、运动开关）
- 云端 LLM：OpenAI 兼容 + Anthropic 兼容双协议，配置全在 SD 卡
- **语音链路**（用户已拍板直接上）：ESP-SR 唤醒 → 录音 → STT → LLM → TTS → 扬声器
- **上位机接口（遥测+控制）**：冻结 WebSocket JSON 协议 v1 + 固件侧实现；PC 端程序为后续独立工程

用户拍板的三个决策：① 语音链路本计划就做；② 运动按低速设计，**当前电机不接线**，但计算出的输出参数必须显示在 debug 叠加层；③ 上位机 = 遥测+控制双向。

硬件就绪状态：**相机、屏幕、SD、C6 WiFi、音频 = 板载就绪**；电机/编码器/INA219/IMU/BH1750 = 暂不接（驱动保留，探测缺席降级）。

---

## 1. 已核实事实（执行时直接引用，勿再查证）

### 1.1 板卡（Waveshare ESP32-P4-WIFI6，实测来源 testP4/board_pins.h + docs/BOARD_MAPPING.md）

| 资源 | 事实 |
|---|---|
| Flash / PSRAM | 板载 16MB flash（当前 sdkconfig 只配了 8MB，本计划改 16MB）；32MB PSRAM（200MHz HEX 已配好） |
| TF 卡 | 固定引脚 CLK=43 CMD=44 D0=39 D1=40 D2=41 D3=42，板载 10k 上拉；**testP4 实测用 SDSPI 模式挂载成功**（CMD=MOSI、D0=MISO、D3=CS，`sd_pwr_ctrl_new_on_chip_ldo` LDO_VO4 供电必须开）。照抄 `testP4/main/sd_storage.c` |
| 板载 I2C0 | GPIO7/8（SDA=7 SCL=8），挂 ES8311(0x18?)、触摸 FT6x36(0x38)、**相机 SCCB OV5647(0x36)**。NanoSoul 现有代码没碰它，需要新建 board_i2c0 模块 |
| 音频 | ES8311 + NS4150B 功放；I2S0：MCLK=13 BCLK=12 WS=10 DOUT=9 DIN=11(录音)，PA_EN=GPIO53 高有效。播放路径 testP4 已验证（`audio_player.c`），**录音路径未验证 = 风险项** |
| 相机 | OV5647 MIPI-CSI；CSI 与 DSI **共用 MIPI DPHY 轨 LDO_VO3 @2500mV**。esp_video 默认 CSI LDO 单元不对，**必须打 cmake 补丁**（照抄 `testP4/cmake/patch_esp_video_ldo.cmake`，改 `CSI_LDO_UNIT_ID=3`、`CSI_LDO_CFG_VOL_MV=2500`） |
| 屏 | WLK2802 ST7701S 2.8" **480 宽×640 高竖屏**，1-lane DSI @700Mbps，DPI 25MHz；已在 `components/display/` 点亮，`st7701.h` 暴露 `st7701_get_panel()` + `st7701_register_color_trans_done_callback()` |
| C6 WiFi | 经 SDIO + esp_hosted，**C6 固件板载预刷**；host 侧组件 `espressif/esp_wifi_remote ^1.5.1` + `espressif/esp_hosted ^2.12.6`（testP4 实测版本，扫描/连接/ping 通过，照抄 `app_wifi.c`） |
| USB | GPIO24/25 = USB D-/D+（USB-Serial-JTAG）。**当前无 PCB 电机映射 M1 IN1/IN2 = IO24/25 与之冲突**——电机一使能串口日志断。本阶段电机不接线所以不触发；接线阶段前须挪 M1 引脚或接受丢串口 |
| 保留脚 | IO35-38 strapping；IO39-44 TF；IO9-13+53 音频；IO7/8 I2C0；RXD/TXD 调试 UART |

### 1.2 NanoSoul 现有固件（无 PCB 模块版引脚 = CLAUDE.md「固件」节）

- 电机 LEDC 20kHz 10-bit（`MOTOR_DUTY_MAX=1023`），M0: PWM2/IN1=3/IN2=4，M1: 5/24/25，M2: 26/27/32；STBY 分两脚 IO51(M0/M1)+IO52(M2)；编码器 PCNT ×4 正交（M0=30/31 M1=28/29 M2=46/47，`ENC_COUNTS_PER_REV=28` 电机轴）；I2C1=IO20/21 @100kHz 挂 INA219(0x40，absent 容错已实现)。perfboard 分支有未提交的"单电机→三电机数组化"改动，**先提交再开新分支**。
- `components/display/` 与 emote 引擎不并存（两套渲染器）——docs/07 已定 Kconfig 二选一方案。

### 1.3 组件版本（全部在 IDF 5.5.2 + 本板验证过或官方声明支持 P4）

| 组件 | 版本 | 来源/用途 |
|---|---|---|
| `espressif/esp_video` | `^0.8` | 相机 V4L2 管线（testP4 实测） |
| `espressif/esp_wifi_remote` | `^1.5.1` | C6 WiFi host API（testP4 实测） |
| `espressif/esp_hosted` | `^2.12.6` | SDIO 传输层（testP4 实测） |
| `espressif/esp_lcd_st7701` | `^2.0.0` | 已在用 |
| `espressif/human_face_detect` | `^0.5.0` | 人脸检测，**明确支持 ESP32-P4**；C++ API：`HumanFaceDetect detect; detect.run(dl::image::img_t{data,width,height,pix_type})`；模型可放 flash 分区（**分区名必须 `human_face_det`**）或 rodata |
| `esp_emote_gen_player`（本地 vendored） | 0.0.2 | 表情引擎，依赖 `espressif2022/esp_emote_gfx ^3.0.0`（docs/07 已查证） |
| `espressif/esp-sr` | 最新（P4 支持自 v1.9.0） | AFE+WakeNet9；唤醒词候选 `wn9_nihaomiaoban_tts2`；模型放 `srmodel` 分区 |
| `espressif/esp_codec_dev` | `^1.5` | ES8311（testP4 实测播放） |
| `lvgl/lvgl` | 9.2.2 | 仅 TESTPANEL 模式保留 |

### 1.4 云端 API 形态（已核对 claude-api 参考）

- **Anthropic 兼容**：`POST {base_url}/v1/messages`，头 `x-api-key: <key>`、`anthropic-version: 2023-06-01`、`content-type: application/json`；体 `{model, max_tokens, system, messages:[{role:"user",content:"..."}]}`；回复取 `content[]` 中 `type=="text"` 块；`stop_reason=="refusal"` 需处理（显示 sad/致歉文案）。多轮=客户端自持历史。默认 model 示例 `claude-opus-4-8`。
- **OpenAI 兼容**：`POST {base_url}/v1/chat/completions`，头 `Authorization: Bearer <key>`；体 `{model, messages:[{role:"system"},{role:"user"},...]}`；回复取 `choices[0].message.content`。
- **STT/TTS 走 OpenAI 兼容音频端点**（Anthropic 无语音）：STT=`POST {base}/v1/audio/transcriptions`（multipart WAV，字段 model/file）；TTS=`POST {base}/v1/audio/speech`（`response_format:"wav"` 便于直接播放）。STT/TTS 端点允许与 chat 用不同 provider（SD 配置分开三段）。
- 全部走 `esp_http_client` + esp-tls，`CONFIG_MBEDTLS_CERTIFICATE_BUNDLE=y`。非流式起步（max_tokens ≤512，桌面机器人短回复）。

### 1.5 已知坑（每条都有实证，实现时直接规避）

1. **esp_video CSI LDO**：不打补丁相机必挂（testP4 commit "Fix camera CSI DPHY LDO rail"）。
2. **CSI 偶发崩溃**：开 `CONFIG_CAM_CTLR_MIPI_CSI_ISR_CACHE_SAFE=y`（docs/02 附录）。
3. **emote 包名字段 16B**：`CONFIG_MMAP_FILE_NAME_LENGTH=16`（docs/07 坑#4）。
4. **emote `anim_fade` 在 gfx 回调里死锁**：切表情必须走队列+专职任务（docs/07 坑#3）。
5. **表情素材 640×480 横 vs 屏 480×640 竖**：flush 路径旋转 90°（P0 CPU 转置，后续 PPA），docs/07 已定方案。
6. **SD 用 SDSPI 不用 4-bit SDMMC**：testP4 的选择（实测可挂载）；配置文件读写吞吐足够。必须先 `sd_pwr_ctrl_new_on_chip_ldo(chan 4)`。
7. **人脸检测模型分区名固定 `human_face_det`**（组件按 label 找）。
8. **esp-dl 是 C++**：vision 组件用 .cpp 实现 + `extern "C"` C 门面，其余组件保持 C。
9. **两套渲染器不并存**：FACE 模式（emote gfx + HUD 标签）与 TESTPANEL 模式（LVGL 电机面板）Kconfig 二选一，默认 FACE。
10. **IO24/25 = USB 串口**：电机 M1 使能即断串口日志（本阶段不接线不触发，接线前解决）。
11. 相机 SCCB 挂在板载 I2C0(7/8)，与外设 I2C1(20/21) 是两条总线，别混。
12. PPA（`driver/ppa.h`）P4 硬件缩放/旋转可用（testP4 相机 240×240 预览实测）；HW JPEG（`driver/jpeg_encode.h`）可用（拍照存 SD 实测）。

---

## 2. 总体架构

```
main/                    app_main：按序初始化 + Kconfig 模式选择（FACE 默认 / TESTPANEL 保留）
components/
  display/               [已有] st7701 面板底座（两种模式共用）
  face/                  表情执行器（docs/07：emote player + 旋转 flush + 切换队列）
  hud/                   debug 叠加层：gfx_label 若干行贴在表情画布上，2Hz 刷新，消费 telemetry
  telemetry/             全局状态注册表（单写多读结构体+互斥）+ esp_event 自定义事件总线
                         —— HUD、WebSocket、串口日志三个消费端共用这一份数据
  storage_sd/            SDSPI 挂载(/sdcard) + config.json 解析(cJSON) + 缺省值/热重载接口
  vision/                esp_video V4L2 相机 + HumanFaceDetect 封装（.cpp + C 门面）
                         输出 face_obs_t{present, cx, cy, area_ratio, frontal_score, ts}
  motion/                三轮全向 IK（vx,vy,wz→三轮转速→duty）+ 输出门控
                         motion.enabled=false 时只算不驱动，结果进 telemetry
  soul/                  决策状态机（自研核心）：吃 vision/系统事件，出 运动意图+表情+tip 文案
  netlink/               esp_hosted WiFi STA + SNTP + mDNS(nanosoul.local) + WebSocket 服务（上位机协议 v1）
  llm/                   双协议 chat 客户端（openai/anthropic）+ STT/TTS 客户端（openai 兼容）
  voice/                 ES8311 录/放（esp_codec_dev）+ ESP-SR AFE/WakeNet + 对话流程编排
  drv_*（main/ 现有）     电机/编码器/INA219 驱动保留，缺席降级
  selftest/              自动循环自检框架（见 §2.1）：各组件注册检查项，上电自动逐项跑并循环烤机，
                         结果上屏 + 串口 JSON，一次刷机拿全量结果，无需人工逐项驱动
```

### 2.1 自动循环自检（selftest，贯穿所有阶段的验收载体）

目的：**Captain 只做两件事——刷固件、回贴串口日志**；剩下的验证与重试由自检循环和执行者自主完成，不需要用户逐步指挥。

- 框架：`selftest_register(name, fn, flags)`；检查函数返回 `{PASS|FAIL|SKIP(硬件缺席), detail[64]}`。启动模式三选一（Kconfig `NANOSOUL_MODE`：`FACE`(默认) / `SELFTEST` / `TESTPANEL`），SELFTEST 也可由 WS 命令 `selftest {}` 或串口命令随时触发单轮。
- 运行方式：上电自动跑全部检查项 → 屏上显示 PASS/FAIL 矩阵 → **进入循环烤机**（每轮间隔 5s，长跑统计累计失败次数/掉线次数）。串口每项输出一行机器可读 JSON：`{"st":"selftest","item":"sd_mount","pass":true,"detail":"16GB FAT","round":3}` —— 执行者直接 grep 日志定位问题、改码、再出固件，**自主迭代到全绿，不逐步请示**。
- 检查项随阶段累积注册：
  - Phase 0：`sd_mount`、`config_parse`、`psram`、`partition_layout`
  - Phase A：`emote_mount`（合包 index 条目数）、`emote_cycle`（5 情绪各切一遍，渲染帧计数增长）、`hud_draw`
  - Phase B：`i2c0_probe`（SCCB 0x36 应答）、`camera_stream`（1s 内出帧数≥5）、`face_detect_bench`（合成/静态帧推理耗时）、真人项标记 MANUAL
  - Phase C：`motion_ik`（给定 (vx,vy,wz) 断言三轮 duty 数值，纯计算可全自动）、`soul_sim`（注入伪 face_obs 序列断言状态迁移 IDLE→APPROACH→ENGAGE→GAZED）
  - Phase D：`wifi_connect`、`sntp`、`llm_ping`（两 provider 各发一条 "ping" 问答，校验非空回复；无 key 则 SKIP）
  - Phase E：`codec_playback`（1kHz 音 1s）、`mic_record`（录 2s 写 SD + RMS 能量阈值判有声）、`wakenet_load`；唤醒实测标 MANUAL
  - Phase F：`ws_loopback`（本机起客户端 ping /ws 收 state 帧）
- `soul_sim`/`motion_ik` 这类纯逻辑项**同时编成板外可跑的宿主单测思路**（不依赖真机的断言放进检查函数，板外至少保证编译期与逻辑评审），真机项 SKIP 降级不算失败。

**任务/核分配（起步值，上板再调）**：core1 = gfx 渲染(prio7) + 相机取流(5)；core0 = 人脸检测(4) + soul 决策(5, 10Hz) + motion 定时器(6, 50ms) + voice/AFE(5) + netlink/llm(3)。检测器输入用 PPA 缩到 ~320×240 RGB565 再喂 `HumanFaceDetect`。

**数据流**：vision → (queue) → soul → {motion 意图, face 表情, tip 文案, telemetry 事件}；voice 唤醒 → soul 进入 LISTEN/THINK/SPEAK 状态；WS 命令 → soul（ask/estop/emotion override）。云端 LLM 永不进感知决策回路（宪法红线）。

**soul 状态机 v1**（阈值全部来自 SD 配置，默认值写进 config 缺省）：

| 状态 | 进入条件 | 表情 | 运动意图 |
|---|---|---|---|
| IDLE | 缺省/无人脸 | waiting | 停（可选慢速扫视，默认关） |
| ENGAGE | 有人脸且 area∈[near_lo,near_hi] | waiting | 转向对中（wz∝cx偏差） |
| APPROACH | 有人脸且 area<near_lo | waiting | 前进+对中，vx=slow |
| RETREAT | area>near_hi | o | 后退 vx=-slow |
| GAZED | ENGAGE 中 frontal_score>阈值 持续 gaze_hold_ms | o（害羞） | 后退一小段后回 ENGAGE |
| LISTEN/THINK/SPEAK | 唤醒/等 LLM/播 TTS | waiting/think/waiting | 停 |
| FAULT | 堵转(有 duty 编码器不动)/致命错误 | sad | 急停(STBY 拉低)+锁定 |

优先级：FAULT > 语音会话 > GAZED/RETREAT > APPROACH/ENGAGE > IDLE。frontal_score 用检测关键点（双眼-鼻对称度 + 双眼距/框宽）；距离代理 = bbox 面积比。

---

## 3. 分区表（16MB，一次全擦到位）与 sdkconfig 增量

```
# Name,       Type, SubType,  Offset,    Size
nvs,          data, nvs,      0x9000,    0x6000
otadata,      data, ota,      0xf000,    0x2000
phy_init,     data, phy,      0x11000,   0x1000
ota_0,        app,  ota_0,    0x20000,   0x320000   # 3.1MB：gfx+esp-dl+esp-sr+hosted 都要进 app
ota_1,        app,  ota_1,    0x340000,  0x320000
emote_gen,    data, spiffs,   0x660000,  0x180000   # 表情合包（docs/07）
human_face_det, data, spiffs, 0x7e0000,  0x200000   # 人脸模型（组件规定此 label）
srmodel,      data, spiffs,   0x9e0000,  0x400000   # ESP-SR 唤醒/AFE 模型
storage,      data, fat,      0xde0000,  0x200000   # 备用
```

sdkconfig.defaults 增量：`FLASHSIZE_16MB`、`MMAP_FILE_NAME_LENGTH=16`、`CAM_CTLR_MIPI_CSI_ISR_CACHE_SAFE=y`、`MBEDTLS_CERTIFICATE_BUNDLE=y`、esp_hosted SDIO 默认、（FACE 模式下不再需要 LVGL 字体项，保留不删以兼容 TESTPANEL）。C++ 支持默认开启无需配置。

## 4. SD 配置 schema（/sdcard/nanosoul/config.json，cJSON，缺字段用内置默认）

```json
{
  "wifi":   { "ssid": "", "password": "" },
  "chat":   { "provider": "anthropic|openai", "base_url": "https://api.anthropic.com",
              "api_key": "", "model": "claude-opus-4-8", "max_tokens": 512,
              "system_prompt": "你是桌面陪伴机器人 NanoSoul，回答简短温暖。" },
  "stt":    { "base_url": "", "api_key": "", "model": "whisper-1" },
  "tts":    { "base_url": "", "api_key": "", "model": "tts-1", "voice": "alloy" },
  "behavior": { "near_lo": 0.04, "near_hi": 0.18, "frontal_thresh": 0.7,
                "gaze_hold_ms": 1500, "idle_scan": false },
  "motion": { "enabled": false, "max_duty_pct": 40 },
  "companion": { "enabled": true, "token": "" },
  "debug":  { "overlay": true, "log_level": "info" }
}
```

规矩：仓库只放 `config.example.json`（docs/ 或 sdcard_template/），**真 key 永不进 git**（CLAUDE.md 红线）。

---

## 5. 分阶段执行（每阶段末：板外 `idf.py build` 必过 + commit；上板项列给 Captain 手动）

### Phase 0 — 底座（分支/分区/SD/遥测）
1. Captain 先提交 perfboard 未提交的三电机改动；从其上开新分支 `soul-app`。把本计划存入 `docs/08_整机程序总体计划.md`。
2. 分区表按 §3 重写 + flash 改 16MB（**下次烧录全擦**，与 Captain 对齐窗口）。
3. `components/storage_sd`：照抄 testP4 `sd_storage.c` 的 SDSPI+LDO_VO4 挂载；实现 config.json 加载/默认值合并；`sdcard_template/` 出模板。
4. `components/telemetry`：状态结构体（motor cmd/enc/current/face/soul state/net/llm/voice/fps/heap）+ 事件总线。
5. `components/selftest` 框架（§2.1）+ Phase 0 检查项；main 骨架：Kconfig `NANOSOUL_MODE`（FACE 默认 / SELFTEST / TESTPANEL），app_main 按序拉起。
   **上板验收**：SELFTEST 模式刷机后自检循环跑起来，串口连续输出各项 JSON 结果；TESTPANEL 模式行为与现状一致。之后各阶段验收一律 = 该阶段检查项在自检循环里全绿（MANUAL 项除外），Captain 只刷机+回贴一段日志。

### Phase A — 表情脸 + debug HUD（执行 docs/07 的 P0+P1，加 HUD）
1. 按 docs/07 落地 `components/face`（旋转 flush、合包管线 tools/emote_repack.py、emote_gen 分区、切换队列）。
2. `components/hud`：在 gfx 画布上建 6-10 行 `gfx_label`（画布坐标系 640×480），2Hz 从 telemetry 刷新：`SOUL:<state> FACE:<x,y,area,frontal> MOT:<vx,vy,wz|d0,d1,d2> ENC:<rpm×3> CUR:<mA|-- > NET:<ip|off> LLM:<idle|think> VOI:<idle|listen|speak> FPS:<render/detect> HEAP:<free>`。`debug.overlay` 可关。
   **上板验收**：5 情绪轮播正常 + HUD 数字实时跳动（此时电机/编码器显示 0/absent 属正常）。

### Phase B — 相机 + 本地人脸检测
1. `board_i2c0` 模块（GPIO7/8 master bus，给相机 SCCB；触摸/编解码器共用留接口）。
2. 移植 testP4 `camera.c`（esp_video V4L2 + mmap 双缓冲 + PPA 缩放）+ **cmake LDO 补丁**进本仓库。
3. `components/vision`：依赖 `espressif/human_face_detect ^0.5.0`；检测任务循环取帧→`HumanFaceDetect::run()`→算 area_ratio/cx/frontal_score→发队列+telemetry；模型烧 `human_face_det` 分区。
4. HUD 显示 bbox 数据与检测 FPS。（可选加分项：GAZED 时 HW JPEG 拍快照存 SD——testP4 已有 `camera_capture_jpeg`。）
   **上板验收**：断网状态下，人进画面 HUD 出现 face 数据，正脸/侧脸 frontal_score 有区分度，检测 ≥5 FPS。

### Phase C — 决策闭环 + 运动输出（不接轮）
1. `components/motion`：三轮全向 IK（120° 布局，轮向量投影，输出三轮目标转速→duty），门控 `motion.enabled`（默认 false：只算不驱动，全量进 telemetry/HUD）；堵转守护（有 duty 且编码器静止 800ms → FAULT）与丢脸即停留作接线后启用。
2. `components/soul`：按 §2 状态机实现；行为触发表情（经 face 队列）；所有状态迁移打 telemetry 事件。
   **上板验收**：人由远及近，HUD 依次显示 APPROACH→ENGAGE→RETREAT 的运动意图数值；盯着看 1.5s 触发 GAZED + 表情变 o；全程断网。

### Phase D — 联网 + LLM 文字链路
1. `components/netlink`：esp_wifi_remote+esp_hosted 依赖；移植 testP4 `app_wifi.c`（STA 连接，凭据来自 SD config）；SNTP、mDNS。
2. `components/llm`：双协议 chat（§1.4 形态），TLS 证书 bundle；请求期间 soul 进 THINK（表情 think）；回复上屏（face tip 文案）；`stop_reason=="refusal"`/HTTP 错误→sad+短提示。串口控制台命令 `ask <text>` 做首个触发器。
   **上板验收**：SD 卡改 provider 分别用 OpenAI 兼容与 Anthropic 兼容端点各问答一次成功；拔网线→请求超时→本地闭环不受影响（表情/检测/决策照跑）。

### Phase E — 语音链路
1. `components/voice`：esp_codec_dev 起 ES8311 全双工 I2S（录 16k/16bit 单声道，DIN=11；放 = testP4 audio_player 路径，PA=53）；**录音路径首次验证，列为本阶段第一个上板项**（先写 raw PCM 到 SD 人耳验听）。
2. 接 ESP-SR：AFE(含 AEC 可后开) + WakeNet9（唤醒词 `wn9_nihaomiaoban_tts2`，模型进 `srmodel` 分区，走 esp-sr 官方 CMake 烧录流程）。
3. 会话编排：唤醒→LISTEN（VAD 截段，≤8s）→STT→chat→TTS(wav)→播放（半双工：播时闭麦）；全程 soul 状态/表情联动；HUD 显示 VOI 状态。
   **上板验收**：喊唤醒词→说一句→机器人语音回答；期间表情 waiting→think→waiting；断网时唤醒后播本地兜底提示音/文案。

### Phase F — 上位机接口（协议冻结 + 固件侧）
1. 协议文档 `docs/09_上位机接口协议_v1.md`（§6 全文照搬冻结）。
2. `components/netlink` 内加 `esp_http_server` + WebSocket `/ws`：连接鉴权（config 的 companion.token，query 参数携带）；遥测推送（telemetry 事件→JSON，状态全量 1Hz + 事件即时）；命令处理（§6 列表）路由到 soul/face/motion/llm。
3. 快照命令：HW JPEG 编码当前帧，WS 二进制帧回传。
   **上板验收**：PC 上用 `websocat`/浏览器控制台连上 `ws://nanosoul.local/ws?token=...`，能看到状态流；发 `ask` 收到 LLM 回复事件；发 `estop` 后 soul 进 FAULT。

> PC 端配套程序（可视化陪伴面板、用户状态长期分析）= 后续独立工程，不在本仓库，本计划只交付协议与固件端点。

---

## 6. 上位机 WebSocket 协议 v1（冻结稿）

- 传输：`ws://nanosoul.local/ws?token=<companion.token>`，LAN only；文本帧 = UTF-8 JSON，二进制帧 = JPEG 快照。
- 通用信封：`{"v":1, "type":"<kind>", "ts":<ms since boot>, ...}`；未知 type 必须忽略（前向兼容）。
- 机器人→PC：
  - `state`（1Hz 全量）：`{soul, emotion, face:{present,cx,cy,area,frontal}, motion:{intent:[vx,vy,wz], duty:[d0,d1,d2], enabled}, enc_rpm:[..], current_ma|null, net:{ip,rssi}, llm:"idle|busy", voice:"idle|listen|think|speak", heap, fps:{render,detect}}`
  - `event`（即时）：`{name:"soul_transition|gazed|wake|llm_reply|fault|...", data:{...}}`；其中 `llm_reply.data={text}`——用户状态类事件（在席/离席、被注视时长、互动次数）都从这里出，供 PC 端做陪伴分析。
  - `snapshot`（二进制 JPEG，响应 get_snapshot）
- PC→机器人（命令，均回 `{"type":"ack","id":...,"ok":bool,"err":...}`）：
  - `ask {text}` 文字问答（复用 llm 链路，回复走 llm_reply 事件）
  - `set_emotion {name, mode:"now|fade"}` 表情覆盖（10s 后回归状态机）
  - `teleop {vx,vy,wz,ttl_ms}` 遥控运动（仅 motion.enabled 时生效，ttl 到期自动停）
  - `get_snapshot {}`、`estop {}`、`config_reload {}`、`set_overlay {on}`

---

## 7. 风险清单（按杀伤力排序）

| 风险 | 缓解 |
|---|---|
| ES8311 录音路径从未验证（板载麦→AFE 增益/时钟） | Phase E 第一步单测录 PCM 到 SD；不行则回退 UAC/外接麦排查；语音整段可降级为文字通道（Phase D 已可用） |
| app 超 3.1MB（gfx+esp-dl+esp-sr+hosted+TLS 同仓） | 分区留了余量；仍超则裁 tip 字体(700KB)/esp-sr AFE 精简/压 ota 到 2.75M×2 |
| 检测帧率不足或误检多 | 输入降到 240×240、检测跳帧、结果 3 帧滑窗滤波；espdet 系列可换 |
| esp_hosted 与 CSI/DSI/SDSPI 总线并发稳定性 | testP4 分项验证过但没同时全开；Phase D 上板做 30min 全负载烤机，掉线自动重连 |
| GAZED 误触发（正脸度阈值） | 阈值进 SD 配置可现场调；HUD 实时显示 frontal_score |
| 16MB 分区重排 = 全擦 | 与 Captain 烧录窗口对齐，一次到位（Phase 0 就切） |
| IO24/25 vs USB 串口（接线阶段） | 本计划不触发；接电机前在 BOARD_MAPPING 里重排 M1 或改用 WS 遥测代替串口日志 |
| LLM/STT/TTS 端点延迟高 | 非流式+短回复；think 表情掩护；超时 8s 落 sad+兜底文案（断网演示本就是卖点） |

## 8. 纪律

- **执行者自主迭代，不逐步请示**：build 失败自己改自己重编到过；自检 FAIL 拿串口日志自己定位、改码、出下一版固件，直到该阶段检查项全绿才向用户汇报。只有「需要真机重刷/回贴日志」「破坏性操作」「方案级改向」才找用户。
- 每阶段 commit 前 `idf.py build` 板外必过（FACE / SELFTEST / TESTPANEL 三模式都编）；flash/monitor/上板验收全部 Captain 手动，不进共享任务。
- AI 产出的上电顺序/LDO/引脚配置人必复核（宪法）；真 key 不进仓库。
- 引脚如有变动同步 CLAUDE.md「固件」节 + `docs/BOARD_MAPPING.md`；本计划落库为 docs/08，协议落库为 docs/09；docs/07 保持为表情子计划真值。
- 复用优先：能照抄 testP4/官方组件的不重写；自研精力集中在 soul 状态机、motion IK、频道编排。

## 9. 端到端验证（比赛演示映射）

最终一条龙（断网开始）：上电→表情 idle→人走近→APPROACH/ENGAGE 意图数值上屏→盯视 1.5s→GAZED 害羞退后→喊唤醒词（联网后）→问答→语音回答+think 表情→PC 上位机全程看到遥测流。此即演示脚本的"本地视觉感知+自主行为+对话"三段，断 WiFi 后前两段照常 = 比赛杀手锏。

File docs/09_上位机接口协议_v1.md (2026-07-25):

# 09 · 上位机接口协议 v1（冻结）

> NanoSoul 与电脑上位程序之间的 WebSocket 接口。固件实现位于 `components/companion/`。
> v1 已冻结。当前实现有三项已知差异：ack 不含 `v/ts`，snapshot 时序与本文不同，teleop 的 ttl 尚未实现。
>
> 上位机用于查看机器人状态、接收事件并发送控制命令。
>
> **测试扩展见 [`13_测试模式与上位机_v1.md`](13_测试模式与上位机_v1.md)**：对本协议做加法（`hwinfo`/`sense` 帧、`override_set`/`inject_event`/`motor_test` 等命令 + 串口 NDJSON 通道），用于真机硬件测试与传感数值覆盖。本文（v1 冻结）不变。

## 传输

- `ws://nanosoul.local/ws?token=<companion.token>` —— **仅局域网**。token 来自 SD 配置 `companion.token`，不匹配直接拒绝握手。
- 文本帧 = UTF-8 JSON；二进制帧 = JPEG 快照。
- 通用信封：`{"v":1, "type":"<kind>", "ts":<开机毫秒>, ...}`。
- **前向兼容规则**：收到未知 `type` 时忽略，不报错；已有字段的语义保持不变。

## 机器人 → PC

### `state`（1Hz 全量心跳）
```json
{
  "v":1, "type":"state", "ts":123456,
  "soul":"ENGAGE", "emotion":"waiting",
  "face":{"present":true, "cx":-0.12, "cy":0.05, "area":0.09, "frontal":0.71},
  "motion":{"intent":[0.0,0.0,0.10], "duty":[0,-102,102], "enabled":false},
  "enc_rpm":[0,0,0], "current_ma":null,
  "net":{"ip":"192.168.1.42","rssi":-58},
  "llm":"idle", "voice":"idle",
  "heap":210000, "fps":{"render":18.0,"detect":6.2}
}
```

### `event`（即时）
```json
{"v":1,"type":"event","ts":123456,"name":"soul_transition","data":{"from":"IDLE","to":"APPROACH"}}
```
`name` 取值与 `data`：
| name | data | 陪伴分析含义 |
|---|---|---|
| `soul_transition` | `{from,to}` | 行为状态流转 |
| `face_present` / `face_lost` | `{}` | 主人在席 / 离席（陪伴在席率） |
| `gazed` | `{}` | 一次「被注视」触发（专注互动） |
| `wake` | `{}` | 语音唤醒（主动交互次数） |
| `llm_reply` | `{text}` | 一轮对话回复文本 |
| `fault` | `{text}` | 故障（堵转/错误） |
| `selftest_item` | `{name,result,detail,round}` | 自检项结果 |

> 用户状态类分析（在席时长、被注视累计、互动频次、情绪分布）由 PC 端从上述事件流聚合，固件只负责如实上报，不在设备侧做长期统计。

### `snapshot`（二进制）
一帧 JPEG（当前检测帧，300×480），响应 `get_snapshot`。

## PC → 机器人（命令）

每条命令 `{"v":1,"type":"<cmd>","id":<n>, ...}`，机器人回 `{"type":"ack","id":<n>,"ok":true|false,"err":"..."}`。

| cmd | 字段 | 动作 |
|---|---|---|
| `ask` | `{text}` | 文字问答，复用 LLM 链路；回复走 `llm_reply` 事件 |
| `set_emotion` | `{name, mode:"now"|"fade"}` | 表情覆盖，10s 后回归状态机 |
| `teleop` | `{vx,vy,wz,ttl_ms}` | 遥控运动，仅 `motion.enabled` 生效，ttl 到期自动停 |
| `get_snapshot` | `{}` | 回一帧 JPEG 二进制 |
| `estop` | `{}` | 进 FAULT，急停锁定 |
| `clear_fault` | `{}` | 解除 FAULT |
| `config_reload` | `{}` | 重读 SD 配置 |
| `set_overlay` | `{on:bool}` | 开关 debug HUD |
| `selftest` | `{}` | 触发一轮自检 |

## PC → 机器人：状态上报 `pc_state`（v1.1 增补，2026-07-05）

> 上位机不只是控制端，也是**信息源**：把「主人在电脑上的状态」以粗粒度枚举喂给机器人，供本地决策融合（交互策略见 12 §3.5）。属加法演进：老固件收到未知 type 会回 `ack {id:0, ok:false, err:"unknown cmd"}`（实现怪癖），上位机对无法按 id 关联的 ack 一律静默忽略；识别 `pc_state` 的固件**不回 ack**。

```json
{"v":1, "type":"pc_state", "ts":<上位机毫秒>,
 "activity":"active",   // active(有输入) | idle(无输入) | locked(锁屏/屏保)
 "idle_s":37,            // 距最后一次输入的秒数
 "focus":"work",         // work|meeting|media|browse|comm|other|unknown（前台应用类别）
 "media":false,          // 是否正在播放音视频
 "dnd":false }           // 用户手动勿扰开关
```

- 节奏：**变化即发 + 5s 心跳**。设备侧 15s 未更新 → 视为「无 PC 信息」，回退纯视觉行为。
- **隐私边界（硬性）**：只传上述枚举与秒数；窗口标题 / URL / 应用名 / 按键内容一律不出上位机，应用→类别映射在 PC 本机完成。
- 设备侧消费：companion 收帧 → telemetry 快照新增 `pc{...}`（带新鲜度）→ soul 注意力融合（12 §3.5）。`ts` 为上位机自身毫秒钟，设备只用到达时间。

## 安全 / 边界

- LAN only，token 鉴权；不暴露公网。
- `teleop` 在 `motion.enabled=false`（未接轮）时 `ack ok:false err:"motion disabled"`。
- 破坏性/外部动作（此协议内仅 `estop`）立即执行；其余命令幂等或可回退。

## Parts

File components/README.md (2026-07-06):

# components/ — 整机组件

NanoSoul 整机固件的自研/移植 ESP-IDF 组件，每个一个子目录（`CMakeLists.txt` + 对外头文件即接口）。分层、数据流与任务分配总览见 [`docs/00_成品全景与技术框架.md`](../docs/00_成品全景与技术框架.md) §2.4–§3。

| 层 | 组件 |
|---|---|
| 地基 | `telemetry`（遥测快照 + 事件总线）· `storage_sd`（SDSPI 挂载 + config.json）· `bsp` / `board_i2c0` · `selftest` |
| 感知 | `camera`（esp_video/V4L2 + PPA 降采样）· `vision`（ESP-DL 人脸检测） |
| 决策 | `soul`（10Hz 本地状态机） |
| 表达 | `face`（emote 播放器薄封装 + 90° 旋转 flush）· `hud`（遥测叠层） |
| 运动 | `motion`（三轮全向 IK + 输出闸） |
| 语音/云 | `audio`（ES8311 录放）· `voice`（会话流水线）· `llm`（双协议 chat + STT/TTS）· `dialog`（单轮对话编排） |
| 网络/接口 | `netlink`（C6 WiFi + SNTP + mDNS）· `companion`（上位机 WebSocket） |
| legacy | `display`（仅 TESTPANEL 模式的 ST7701 + LVGL 面板，与 emote gfx 链无关） |

约定：

- 现成有官方组件的（BH1750、PCNT、esp_video、esp_codec_dev、esp_hosted …）走 managed components，**不在这里重写**。
- 无 PCB 外接件驱动（TB6612 / 编码器 / INA219）在 `main/drv_*`，不在此。
- 悬崖红外（ITR20001）本版已砍（`docs/04` D-017），IMU 兜底。
- 待补组件：QMI8658 IMU 接入（用 SensorLib/waveshare 现成驱动，非自研）、BH1750 接入、堵转保护闭环——见 `docs/00` §5 差距清单。

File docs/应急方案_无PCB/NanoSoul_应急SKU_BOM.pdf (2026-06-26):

# NanoSoul 无 PCB 应急方案 · 模块级 SKU BOM

桌面陪伴机器人 · 自制载板 PCB 的后备方案：现成模块 + 杜邦线 + 绝缘胶带手工搭建 | 计算核心 = Waveshare ESP32-P4-WIFI6 开发板（已有，从两排

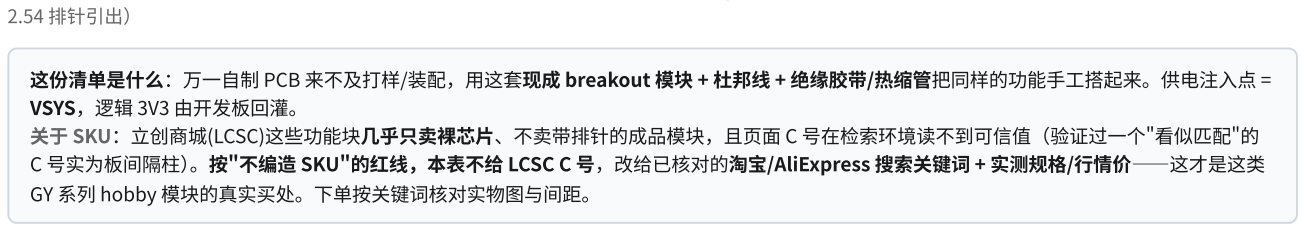
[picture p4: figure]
2.54 排针引出）; VSYS，逻辑 3V3 由开发板回灌。; 关于 SKU：立创商城(LCSC)这些功能块几乎只卖裸芯片、不卖带排针的成品模块，且页面 C 号在检索环境读不到可信值（验证过一个"看似匹配"的; GY 系列 hobby 模块的真实买处。下单按关键词核对实物图与间距。

这份清单是什么：万一 自制 PCB 来不及打样/装配，用这套现成 breakout 模块 + 杜邦线 + 绝缘胶带/热缩管把同样的功能手工搭起来。供电注入点 =

C 号实为板间隔柱）。按"不编造 SKU"的红线，本表不给 LCSC C 号，改给已核对的淘宝/AliExpress 搜索关键词 + 实测规格/行情价——这才是这类

⚠️ 下单前必须定（你的新方案：开发板=电脑供电 / 电池=只带电机 / 外部充电）

1. ★【最关键】共地：开发板 GND（电脑 USB 地）与电池/电机 GND 必须接通成一点，否则 TB6612 信号和 I²C 全乱。这条比什么都重要。
2. 这套方案把原来最大的电源坑全绕开了：开发板吃电脑 USB（不用升压、不会 WiFi6 峰值掉电）；电池只带电机（电流小，TP4056 也不会跳）。 原先那些 TPS61088/大 BMS 的担心都不需要了。
3. 电机轨 XL6009（你已换）升 5.5V：它 datasheet 推荐输入 ≥5V，吃电池 3.7V 属超下限——常态电机 ~0.75A 够用；若堵转明显跌压，① 选 MP 级低堵转 N20，或 ② 干脆电机直接吃电池 3.7V 不升压（更简单，速度略低 ~8%）。
4. N20 电机：带编码器 6 线、MP 级低堵转（~0.67A），别买 HP 级(1.6A)。
5. 大电流（电池/5.5V/电机线）走粗杜邦或焊洞洞板；面包板只走 3V3 和信号。
6. 总开关 ≥3A，串 TP4056 的 OUT+。
7. MAX17048：VLogic→3V3、Bat→电池+；QMI8658：走 I²C（你这块无 CS 脚）、ADO 定地址 0x6A/0x6B。
8. 提醒：开发板用电脑供电=有线连着电脑，机器人移动受限——适合先把功能跑起来的调试阶段；以后要无线移动再上电池供开发板那套(需 5V/ ≥2A 升压+大电容)。

## 汇总采购表

# | 功能 | 推荐模块 | 淘宝关键词 | 数量 | 单价≈ | 备注

1 | 电池保护 (DW01A+FS8205A) | 1S 锂电保护板 | 1S锂电池保护板 过充过放 | 1(+备) | ¥0.5~2 | 选 3A+ 大电流版；若用带保 护版 TP4056 可省此块
2 | 充电+5V升压+电量计 (IP5306 I²C) | TP4056带保护 + MT3608 + MAX17048 推荐替代 | TP4056 Type-C 带保护 / MAX17048 模块 | 各1 | ¥3+2+30 | 比 IP5306 I²C 更可控，且能 读真实电量%/电压
2′ | (赌一把) 同上一块板 搞定 | IP5306 I²C 模块 (PB01) 高风险 | IP5306 I2C 模块 / PB01 IP5306 | 1 | ¥5~12 | ⚠️批次常砍 I²C、到货靠运 气；电量计只有 4 档(25%)
3 | 电机轨升压 5.5V (MT3608) | MT3608 可调升压模块 | MT3608 升压模块 可调 2A | 1 | ¥1~2 | 空载调到 5.5V；够电机轨 0.6A
3b | 开发板 5V 升压 (VSYS) | XL6009 升压模块 (4A) 改用 | XL6009 升压模块 4A 可调 | 1 | ¥3~5 | ⚠️别用 MT3608(出力~1.3A 不够)；调到 5.0V 接 VSYS。 先确认 VSYS 能否直吃电池则 可省
4 | 电机驱动 (2×TB6612FNG) | TB6612FNG 模块（备选 DRV8833） | TB6612FNG 电机驱动模块 | 2 | ¥4~8 | 每块驱 2 路；VCC接3.3V；两 块 STBY 并联=全急停
5 | N20 编码减速电机 6V | GA12-N20 6V 霍尔编码电机 | N20 编码器电机 6V 霍尔 | 3 | ¥15~30 | 减速比 1:50~1:100 三个统 一；编码器供 3.3V；别买无 编码版
6 | IMU 6 轴 (ICM-42688-P) | QMI8658 模块(你已选) 现货 | QMI8658 模块 | 1 | ¥8~20 | 走 I²C(SDA/SCL/INT/ADO)； 与 BH/INA/MAX 同总线，地 址不冲突
7 | 环境光 (BH1750FVI) | GY-302 BH1750 模块 直接平替 | GY-302 光照传感器 | 1 | ¥3~6 | 原设计直接平替，无替代之 忧；ADDR 悬空=0x23
8 | 电机电流检测 (shunt→ADC) | GY-INA219 模块 | INA219 电流传感器模块 | 1 | ¥6~12 | 比手焊 shunt 干净、读真实电 流；可省→纯编码器堵转判定
9 | 电源键 (IP5306 KEY) | 带线轻触按钮 | 带线轻触按钮 焊线 | 1 | ¥0.2~0.5 | 一端接 KEY、一端接 GND （点动非自锁）
10 | 指示灯 | LED+电阻 / 带线灯 | LED 指示灯 带线 3V | 0~2 | ¥0.1~0.5 | 模块自带电量灯/充电灯则可 省
11 | 杜邦线 | 三色套装 20cm（公母/母母/公 公） | 杜邦线 公母 母母 40P 20cm | 1~2套 | ¥10~18 | 母-母买最多（开发板与模块 多为公针）

# | 功能 | 推荐模块 | 淘宝关键词 | 数量 | 单价≈ | 备注

11 | 绝缘 | PVC 电工胶带 + 热缩管套装 | PVC电工胶带 / 热缩管套装 560pcs | — | ¥12~25 | 裸露端子/JST 焊点全包；机 器人会晃，绝缘要到位
11 | 电池 | 1S LiPo 3000mAh 带保护板 PH2.0 | 3.7V 锂电池 3000mAh JST 保护板 | 1~2 | ¥18~30 | 插头 PH2.0 非 XH2.54；选 3000 不选 5000(偏大重)
11 | JST 对插线 | PH2.0(电池) + XH2.54(电机) | JST PH2.0 对插线 / XH2.54 对插线 | 2+4 | ¥0.5~1.5/条 | 电池 PH、电机 XH，两者不通 用别混；可插拔免焊死
11 | 总开关 | 带线船型/拨动开关 | 船型开关 带线 KCD1 | 1 | ¥0.5~2 | 串电池正极
— | (可选)电源汇流 | 迷你面包板 / 洞洞板 5×7 | 迷你面包板 / 洞洞板 5x7 | 选 | ¥1.5~8 | 电源主汇流点别全靠面包板， 关键节点焊洞洞板更稳

整套估算（替代组合方案，不含开发板）：约 ¥170~290（MAX17048 约 ¥30）。 万用表视为已有（调 MT3608 输出、量电池/通断、验端子导通）。

⚠️ 选购防买错（版本 / 引脚 不同，最容易踩）

N20 电机：必须买【带编码器·6 线】版，别买无编码 4 线的便宜款（只有电机、没编码器）。
TP4056：买 Type-C + 带保护版（有 Micro/Type-C、带保护/不带保护 之分；带保护版才顶替 1S 保护板）。 MT3608：买可调版（板上有电位器），#1 调 5V、#2 调 5.5V，别买固定输出版。
IMU：ICM-42688-P 走 SPI（认丝印 SCLK/MOSI/MISO/CS/INT）；替代款 QMI8658 走 I²C（SDA/SCL/INT）——引脚不一样，按你买到的那款 接。
电池：插头要 PH2.0（不是 XH2.54），选带保护板成品。 TB6612：各家排针顺序略不同，按模块丝印脚名接（PWMA/AIN1/AIN2/BIN.../STBY/VM/VCC）。
杜邦线：公-母 / 母-母 / 公-公 三种分清，母-母买最多（开发板和模块多是公针）。
MAX17048：商家约 ¥30 偏贵；省钱可不买，改用 2 个电阻分压 → 开发板 ADC 读电池电压（粗略电量，约 ¥0），或接受没有精确电量。

🔋 电池详细参数（按整机峰值电流选，别只看容量）

参数 | 值 / 选型要求 | 说明
类型 | 1S 单节锂聚合物 LiPo（软包） | 桌面机器人用软包合适；也可 1×18650+保护板（更耐用但更重/圆柱形）
标称电压 | 3.7V（满充 4.2V / 过放截止 ~3.0V） | 升压模块从这个电压往上升 5V/5.5V
容量 | 3000mAh ≈ 11.1Wh | 待机 ~9h、连续运动 ~2.5–3h；选 3000 不选 5000（5000 偏大偏重）
持续放电 C 率 | ≥2C（≥6A）推荐 | ⚠️ 整机峰值约 3A；低 C 率(1C)电池在峰值会压降 → 开发板掉电/重启。买标 注 ≥2C 或 ≥5A 放电的
峰值电流需求 | ~3A（WiFi6 突发 + 电机，两路升压一起从电池 抽） | 持续约 1.5A（≈0.5C）
接口 / 保护 | JST-PH 2.0mm 2P，带保护板成品 | 过充 4.25–4.3V / 过放 2.4–2.5V / 过流短路；插头别买成 XH2.54（间距不同插 不上）
充电 | TP4056 限流 1A，0→满 ~3.3h | 1A≈0.33C 安全；充电电流别超电池的充电 C 率
尺寸 / 重量 | 3000mAh 软包约 ~60×40×8mm / ~55–60g | 具体以卖家为准；留够壳内空间与配重
温度 | 充电 0–45°C / 放电 −20–60°C | LiPo 典型；别在 <0°C 充电
循环寿命 | ~300–500 次 | LiPo 典型，容量随循环衰减

⚠️ 两件最可能买不到原型号、必须走替代（重点）

IP5306 I²C 版（#2）：同型号不同批次会砍 I²C，到货是不是 I²C 全凭运气；且就算是 I²C 版，它的"电量计"只有 4 档 LED 段位(25% 台阶)、读不 到真实 SoC%/电压。建议直接放弃赌它，走 TP4056(带保护)+MT3608+MAX17048——每块功能确定、读数准，MAX17048 还能给到 IP5306 给不了的精确电量%。
ICM-42688-P 模块（#6）：成品 breakout 稀有、缺货涨价、市场有假片。建议默认上 QMI8658 模块（国产现货、便宜、Waveshare 生态成 熟；精度略逊 ICM-42688-P 但远优于 MPU6050）。除非你有正品 ICM-42688-P 渠道。改型后 IMU 多半从 SPI 转 I²C → 先更新 docs/BOARD_MAPPING.md 和 pcb/circuit/pins.py 再接线，确认 I²C 地址不撞（QMI8658 0x6B、BH1750 0x23、INA219 0x40，默认不冲 突）。

## 接线 / 供电总则（先看这条再插线）

三条电压轨：① 逻辑 3V3（开发板回灌）→ 给 IMU/BH1750/INA219/编码器/TB6612 的 VCC；② 电机轨 5.5V（MT3608 输出）→ 只给 TB6612 的 VM；③ 电池 VBAT(3.0~4.2V) → 给保护板/充电/升压输入。三轨共地(GND)，但电压别接错——TB6612 的 VCC=3.3V / VM=5.5V 是两个脚， 最容易插反。
共地是底线：所有模块、开发板、电池负极必须连到同一 GND，否则信号/I²C 全乱。 母-母杜邦为主：开发板排针和多数模块都是公针，靠母-母对插；先想好走线再插，关键节点用热缩管包。
可插拔免焊死：电池用 PH2.0、电机用 XH2.54 对插线，方便拆装/换件。
上电顺序：先空载用万用表把 MT3608 调到 5.5V，确认无短路再接电机/驱动；总开关串电池正极，调试时随时断电。

## 逐块接线要点

① 1S 锂电保护板

B+/B- 接电芯， P+/P- 为受保护输出当 VBAT；B- 与 P- 不能短接。过充 4.25~4.3V / 过放 2.4~2.5V。用带保护版 TP4056 则此块省。

② 充电+升压+电量计（推荐替代组合）

TP4056(带保护)：Type-C/Micro 进 → B+/B- 接电池、OUT+/OUT- 出 VBAT（板上 DW01A+FS8205A 顺带顶掉 #1）。MT3608 升到 ~5V 给 VSYS。MAX17048：VCC=3.3V、 I²C(SDA/SCL) 接 I²C1、并接电池正极采电压 → 直接读电压+百分比。电源键改用总开关或 TP4056 旁路。

③ MT3608 升压（电机轨）

IN+/IN- =VBAT， OUT+/OUT- =驱动 VM；空载先调电位器到 5.5V（power.py 设计值 R82k/10k=5.52V，刻意压在 6V 下给保险丝留余量）。三电机同堵转输入逼近 2A 偏紧，吃 力就换 XL6009/SX1308(4~5A)。

④ TB6612FNG ×2（驱 3 路 N20）

每块： VM →5.5V电机轨、 VCC →3.3V、 GND 共地、 STBY →一个 GPIO（两块 STBY 并联，低=全急停）；每电机 = PWMx+xIN1+xIN2(3 线)+AO/BO 接电机。第 1 块驱 2 个电 机、第 2 块驱第 3 个+1 路备用。备选 DRV8833(更便宜、自带过流过温，PWM 直打 IN1/IN2、方向逻辑略改)。

⑤ N20 编码电机 ×3

6 线（颜色以卖家线序表为准）：M+/M- 接驱动 AO/BO；编码器 VCC→3.3V、GND 共地、C1/C2=编码 A/B 接 GPIO（多数板内已带上拉）。三个减速比必须一致，否则全向运 动学标定很痛苦。3 电机编码共占 6 个 GPIO。

⑥ IMU（QMI8658 默认 / ICM-42688-P 若有正品）

SPI：VCC→3.3V / SCLK / MOSI / MISO / CS / INT；I²C(QMI8658/MPU6050)：VCC→3.3V / SDA / SCL / INT。放离电机远点避磁干扰。ICM-42688-P 经核实 32kHz ODR/低噪 声/APEX(Tap=碰撞,Raise/WoM/Tilt=抬起) 完全满足；QMI8658 是现货友好的次优替代。

⑦ GY-302 BH1750（环境光，最省心）

VCC→3.3V、GND、SDA→I²C1(GPIO21)、SCL→I²C1(GPIO22)；ADDR 悬空/接 GND=0x23，接 VCC=0x5C。贴外壳内壁用 4 线引出几十 cm：上拉调小(2.2k~3.3k)、 SDA/SCL 别与电机线长距并行、速率别拉满(≤100kHz 更稳)。1–65535lx 室内绰绰有余。

⑧ GY-INA219（电机电流，可选）

VCC→3.3V、GND、SDA/SCL→I²C1、 Vin+/Vin- 串入电机供电高边（别接反），地址 0x40。可整块省→纯编码器堵转判定（下指令但编码器不动=堵转）；但 CLAUDE.md 写 明"堵转过流保护是硬需求"，求稳建议装。

与传感器核实报告的衔接：原 PCB 方案三颗传感器(ICM-42688-P / BH1750FVI / IP5306-I²C)均经 datasheet 核实满足要求；唯 IP5306 电量只有 4 档(25%)。本应急方案用 MAX17048 替代 IP5306 的电量计，反而拿到了精确电量%+电压——若最终走应急方案，电量 UI 不必再受 4 档限制。

## 详细接线图（电脑供开发板 / 电池带电机 / 已按实物模块）

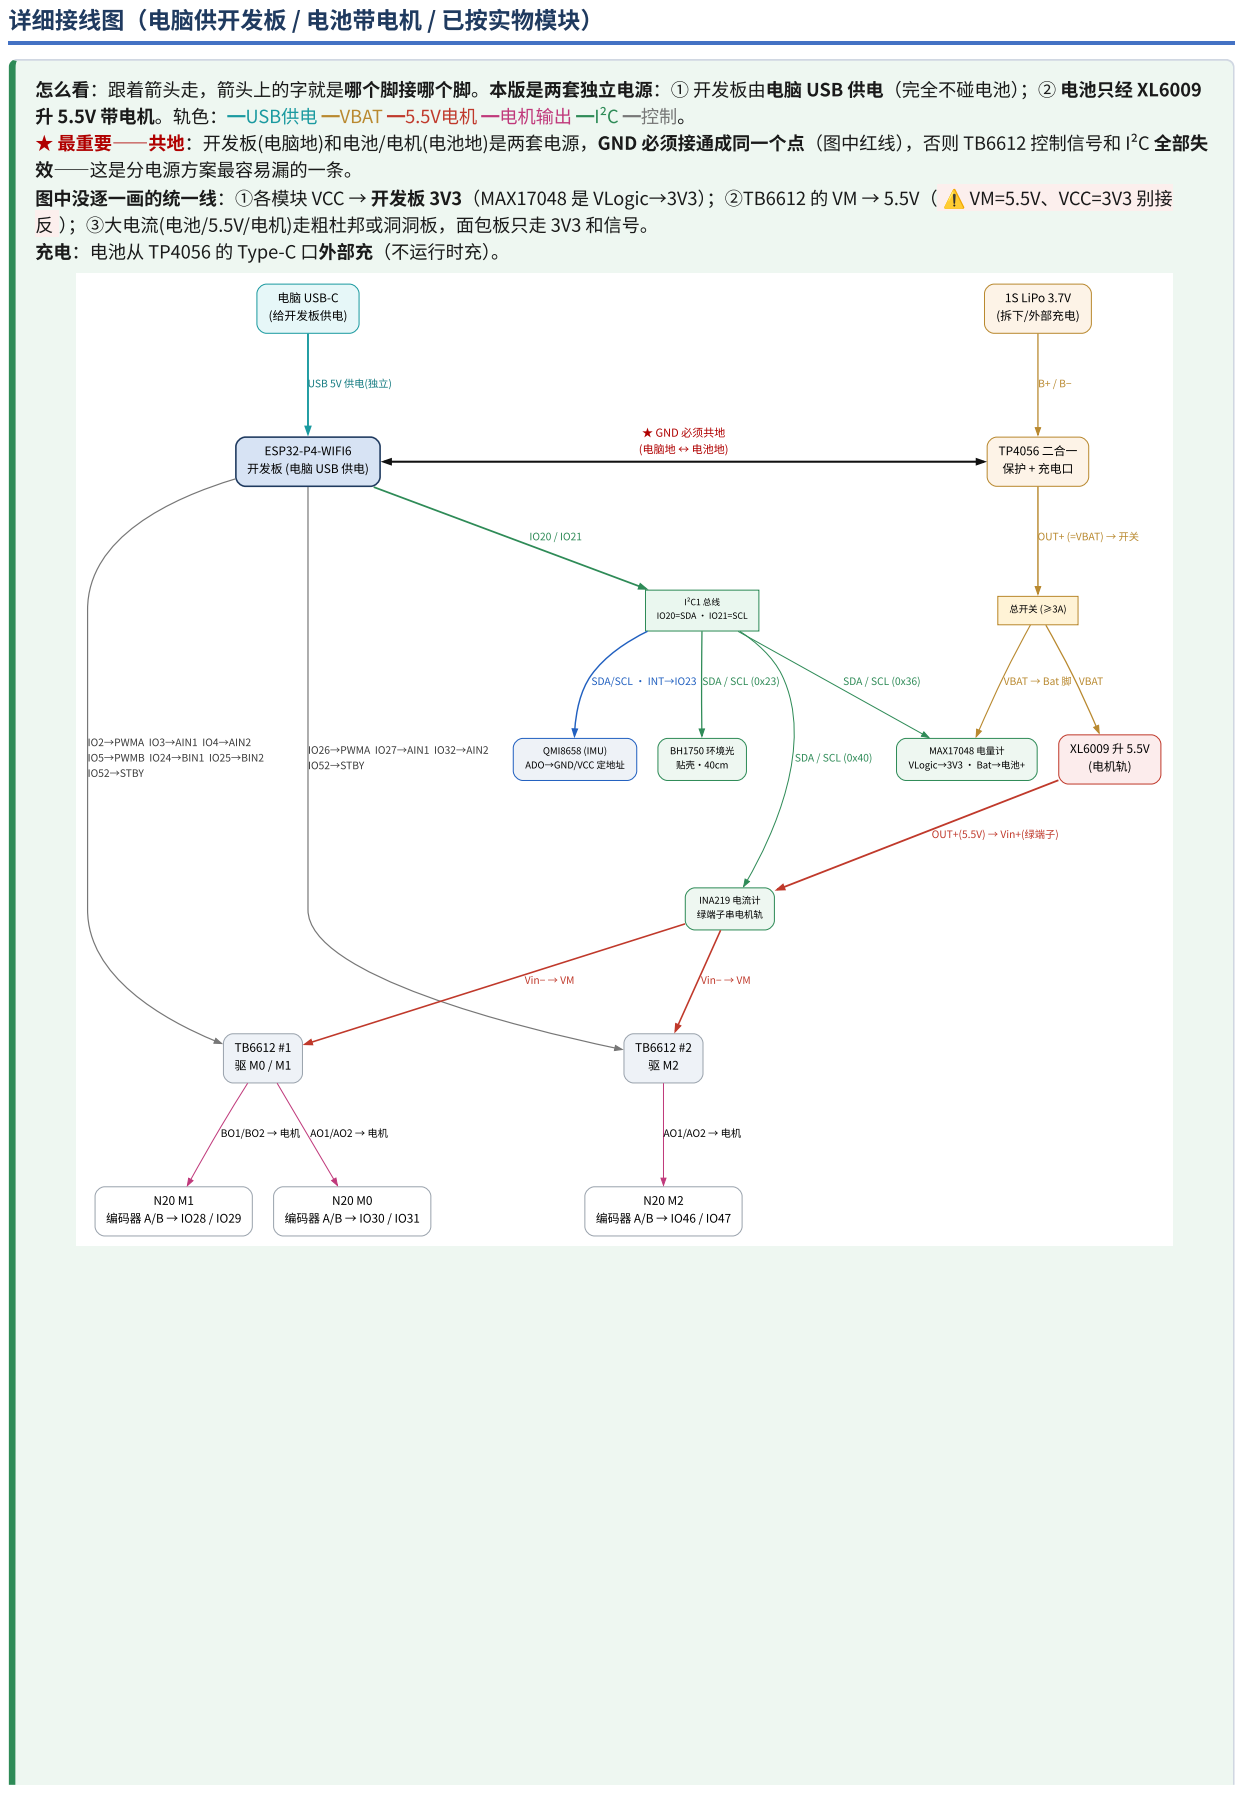
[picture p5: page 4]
图中没逐一画的统一线：①各模块 VCC → 开发板 3V3（MAX17048 是 VLogic→3V3）；②TB6612 的 VM → 5.5V（; ⚠️ VM=5.5V、VCC=3V3 别接; 电脑 USB-C (给开发板供电); TP4056 二合一 保护 + 充电口; ★ GND 必须共地; (电脑地 ↔ 电池地); IO2→PWMA IO3→AIN1 IO4→AIN2 IO5→PWMB IO24→BIN1 IO25→BIN2 IO52→STBY; IO26→PWMA IO27→AIN1 IO32→AIN2 IO52→STBY; I²C1 总线; IO20=SDA · IO21=SCL; 1S LiPo 3.7V (拆下/外部充电); 总开关 (≥3A); XL6009 升 5.5V (电机轨); VBAT; VBAT → Bat 脚; INA219 电流计 绿端子串电机轨; Vin− → VM; N20 M0 编码器 A/B → IO30 / IO31; N20 M1 编码器 A/B → IO28 / IO29; N20 M2 编码器 A/B → IO46 / IO47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

怎么看：跟着箭头走，箭头上的字就是哪个脚接哪个脚。本版是两套独立电源：① 开发板由电脑 USB 供电（完全不碰电池）；② 电池只经 XL6009
升 5.5V 带电机。轨色：━USB供电 ━VBAT ━5.5V电机 ━电机输出 ━I²C ━控制。
★ 最重要——共地：开发板(电脑地)和电池/电机(电池地)是两套电源，GND 必须接通成同一个点（图中红线），否则 TB6612 控制信号和 I²C 全部失
效——这是分电源方案最容易漏的一条。
反 ）；③大电流(电池/5.5V/电机)走粗杜邦或洞洞板，面包板只走 3V3 和信号。
充电：电池从 TP4056 的 Type-C 口外部充（不运行时充）。

USB 5V 供电(独立)

ESP32-P4-WIFI6
开发板 (电脑 USB 供电)

OUT+ (=VBAT) → 开关

SDA/SCL · INT→IO23

QMI8658 (IMU)
ADO→GND/VCC 定地址

MAX17048 电量计
VLogic→3V3 · Bat→电池+

OUT+(5.5V) → Vin+(绿端子)

## 电机 + 编码器（你买的实物）+ 控制参数

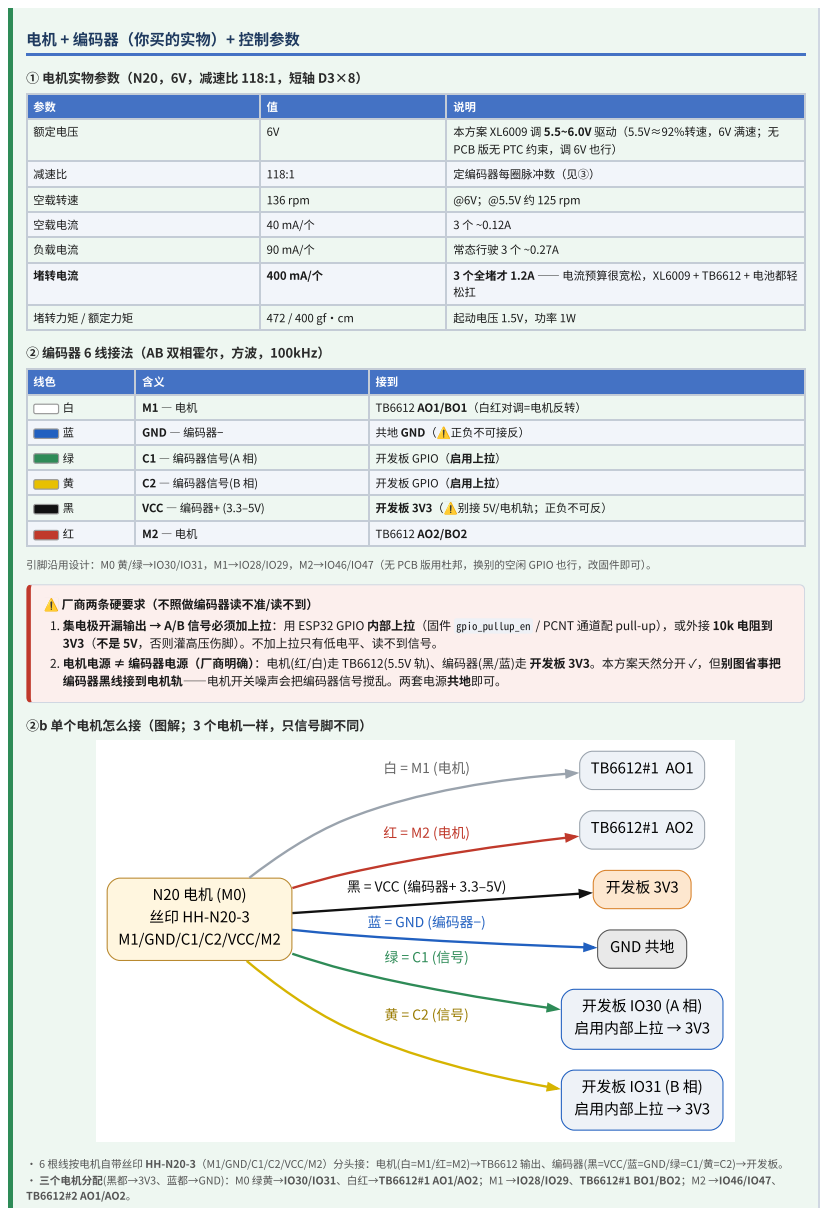
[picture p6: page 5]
N20 电机 (M0) 丝印 HH-N20-3 M1/GND/C1/C2/VCC/M2; 黑 = VCC (编码器+ 3.3–5V); 开发板 3V3; GND 共地; 蓝 = GND (编码器−); 开发板 IO30 (A 相) 启用内部上拉 → 3V3; 开发板 IO31 (B 相) 启用内部上拉 → 3V3

① 电机实物参数（N20，6V，减速比 118:1，短轴 D3×8）

额定电压 | 6V | 本方案 XL6009 调 5.5~6.0V 驱动（5.5V≈92%转速，6V 满速；无 PCB 版无 PTC 约束，调 6V 也行）

减速比 | 118:1 | 定编码器每圈脉冲数（见③）

空载转速 | 136 rpm | @6V；@5.5V 约 125 rpm

空载电流 | 40 mA/个 | 3 个 ~0.12A

负载电流 | 90 mA/个 | 常态行驶 3 个 ~0.27A

堵转电流 | 400 mA/个 | 3 个全堵才 1.2A——电流预算很宽松，XL6009 + TB6612 + 电池都轻 松扛

堵转力矩 / 额定力矩 | 472 / 400 gf·cm | 起动电压 1.5V，功率 1W

② 编码器 6 线接法（AB 双相霍尔，方波，100kHz）

白 | M1 — 电机 | TB6612 AO1/BO1（白红对调=电机反转）

蓝 | GND — 编码器− | 共地 GND（⚠️正负不可接反）

绿 | C1 — 编码器信号(A 相) | 开发板 GPIO（启用上拉）

黄 | C2 — 编码器信号(B 相) | 开发板 GPIO（启用上拉）

黑 | VCC — 编码器+ (3.3–5V) | 开发板 3V3（⚠️别接 5V/电机轨；正负不可反）

引脚沿用设计：M0 黄/绿→IO30/IO31，M1→IO28/IO29，M2→IO46/IO47（无 PCB 版用杜邦，换别的空闲 GPIO 也行，改固件即可）。

⚠️ 厂商两条硬要求（不照做编码器读不准/读不到）
1. 集电极开漏输出 → A/B 信号必须加上拉：用 ESP32 GPIO 内部上拉（固件 gpio_pullup_en / PCNT 通道配 pull-up），或外接 10k 电阻到
3V3（不是 5V，否则灌高压伤脚）。不加上拉只有低电平、读不到信号。
2. 电机电源 ≠ 编码器电源（厂商明确）：电机(红/白)走 TB6612(5.5V 轨)、编码器(黑/蓝)走 开发板 3V3。本方案天然分开 ✓，但别图省事把
编码器黑线接到电机轨——电机开关噪声会把编码器信号搅乱。两套电源共地即可。

②b 单个电机怎么接（图解；3 个电机一样，只信号脚不同）

• 6 根线按电机自带丝印 HH-N20-3（M1/GND/C1/C2/VCC/M2）分头接：电机(白=M1/红=M2)→TB6612 输出、编码器(黑=VCC/蓝=GND/绿=C1/黄=C2)→开发板。
• 三个电机分配(黑都→3V3、蓝都→GND)：M0 绿黄→IO30/IO31、白红→TB6612#1 AO1/AO2；M1 →IO28/IO29、TB6612#1 BO1/BO2；M2 →IO46/IO47、

- 上拉：首选固件 C1/C2 脚启用内部上拉( gpio_pullup_en /PCNT)；读不稳则绿黄各加 10k 到 3V3(长线 4.7k)，不是 5V。
- 方向一致性：上电正转看 PCNT 增/减——要「正 PWM→计数增」，反了对调绿/黄(C1/C2)；白红对调=电机转向反。
- 消噪：电机两端(白–红)并 0.1µF 瓷片(焊电机端子)，抑制电刷火花干扰编码器。

③ 编码器分辨率（固件用 PCNT 正交解码）

- 基础 7 PPR × 减速比 118 = 826 脉冲/圈（单相，输出轴）；正交 ×4（A/B 双边沿）= 3304 计数/圈。
- 用 ESP32-P4 的 PCNT(pulse_cnt) 正交解码（确认 P4 的 PCNT 单元数 ≥3 路；不够则少的那路用 GPIO 中断兜底）。
- 转速 rpm = 计数增量 / 3304 × 60 / Δt(秒)；里程 = 计数 / 3304 × 轮周长。
- 100kHz 响应、5.5V/118:1 满速时单相脉冲率 ≈ 826×(125/60) ≈ 1.7kHz，远在 100kHz 内，PCNT 毫无压力。

④ TB6612 电机控制（每路）

PWM | IN1 | IN2 | 电机
PWM | H | L | 正转（占空比调速）
PWM | L | H | 反转
H | L | L | 滑行 coast
H | H | H | 刹车 brake
L | × | × | 停
STBY = L | | | 全部待机（急停用这个，拉低 IO52）

PWM 频率建议 ~20kHz（超人耳、电机不啸叫；TB6612 支持到 100kHz）。用 ESP-IDF 的 LEDC 或 MCPWM 产生：3 路 PWM + 6 路方向 GPIO + 1 路 STBY。堵转保 护：固件读 INA219 电流 + 编码器不动 → 拉低 STBY 急停。

## 电机驱动板 TB6612 详细接法（含两个 GND 说明）

★ 你问的「两个 GND」：TB6612 板上那 2~3 个 GND 焊盘在板内全部连通，是同一个地——不是"逻辑地/功率地"分开的（TB6612 芯片就一 个地，板子只是多引几个脚方便接线）。接其中任意一个到「系统共地点」即可（接两个更稳、没坏处）。这个共地点 = 开发板 GND(电脑地) ↔ 电池 GND，就是前面反复强调的 ★共地。

① 板上引脚排布（按丝印）

GND 共地 | PWMB IO5 | BIN2 IO25 | BIN1 IO24 | STBY IO52 | AIN1 IO3 | AIN2 IO4 | PWMA IO2
GND 共地 | BO1 M1电机 | BO2 M1电机 | AO2 M0电机 | AO1 M0电机 | GND 共地 | VCC 3V3 | VM 5.5V

↑ 以 TB6612#1(驱 M0=A路 / M1=B路) 为例，按板上丝印排（你的板可能左右镜像，认丝印别认位置）。粉色 = GND（全是同一个地）。

② 每个脚接到哪

脚 | 接到 | 说明
VM | 5.5V 电机轨（XL6009→INA219 Vin−） | 电机功率电源； ⚠️别和 VCC 搞反
VCC | 开发板 3V3 | 逻辑电源 3.3V； ⚠️别接 5.5V
GND(×2~3) | 系统共地点（接一个即可） | 板上几个 GND 同一个地；这点就是开发板地↔电池地的共地
STBY | 开发板 IO52 | 拉高使能、拉低=急停；两块板 STBY 并到同一个 IO52。(想常通也可 接 3V3，但就没急停了)
PWMA | IO2(#1=M0) / IO26(#2=M2) | A 路调速 PWM ~20kHz
AIN1 / AIN2 | IO3·IO4(M0) / IO27·IO32(M2) | A 路方向（真值表见上节④）
AO1 / AO2 | 电机 白(M1)/红(M2) | A 路电机输出
PWMB | IO5(#1=M1)；#2 的 B 路备用空着 | B 路调速
BIN1 / BIN2 | IO24·IO25(M1) | B 路方向
BO1 / BO2 | 电机 白/红 | B 路电机输出

两块板汇总：TB6612#1 → A路驱 M0、B路驱 M1；TB6612#2 → A路驱 M2、B路空着备用。两块板的 VM 都接 5.5V、VCC 都接 3V3、GND 都接共地、STBY 都接 IO52。#2 没用的 B 路（PWMB/BIN1/BIN2/BO1/BO2）悬空即可。

## 怎么装才不烧件（安全装机 / 上电流程）

★ 防烧 7 条铁律

1. XL6009 必须【空载先调到 5.5V】再接电机驱动——升压模块出厂常是直通/高压，不调直接接可能输出十几伏，一秒烧穿 TB6612 和电 机。这是最致命的一条。
2. 所有接线、插拔都在断电下做，绝不带电热插拔（拔插模块的瞬间易打火/接错脚）。
3. TB6612 的 VM(5.5V) 和 VCC(3V3) 是两个脚，别接反——5.5V 灌进 VCC 烧逻辑。
4. MAX17048 的 VLogic 接 3V3、不接电池——接电池会让 I²C 顶到 4.2V，烧开发板的 I²C 脚。
5. 所有传感器(QMI8658 / BH1750 / INA219 / MAX17048)的 VCC 接 3V3，不接 5V/电池——它们都是 3.3V 件。
6. 上电前用万用表查短路：电池+对GND、3V3对GND、5.5V对GND 都不能接近 0Ω（蜂鸣档不响）。
7. 第一次上电手放在总开关上，一闻到糊味/看到冒烟/摸到烫，立刻断电。

① 上电前（断电、用万用表）

- 目检每个模块丝印：VCC/GND 没接反；电池红+黑−；TB6612 VM≠VCC；MAX17048 VLogic≠Bat。
- 通断查短路（蜂鸣档）：电池+↔GND、3V3↔GND、5.5V↔GND 都不响（不短路）。
- 确认共地点已接好（开发板 GND ↔ 电池/电机 GND 接成一点）。

② 分阶段上电（一步一验，别一次全接通电）

步 | 做什么 | 验证 / 注意
1 调压 | XL6009 输入接电池(经总开关)，输出空载，拧电位 器 | 万用表量输出拧到 5.5V → 断电。（此时千万别接 TB6612/电机）
2 开发 板 | 只插电脑 USB，不接任何外设 | 开发板正常开机；量 3V3 脚 = 3.3V
3 共地 | 接开发板 GND ↔ 电池 GND | 这步漏了后面 I²C/电机全不工作
4 传感 器 (低风 险先) | 逐个接 BH1750→QMI8658→INA219→MAX17048，VCC 都接 3V3 | 每加一个跑 I²C 扫描确认地址(0x23 / 0x6A·0x6B / 0x40 / 0x36)。全在 3V3，烧不了大件， 先把弱电链跑通
5 电机 驱动 (大电 流,最 后) | 断电接 TB6612：VM→已调好的 5.5V、 VCC→3V3、GND共地、控制脚→开发板 | 先让电机/轮子悬空，给小占空比 PWM → 量 VM 稳、TB6612 不发烫 → 再正常跑、随时摸 温度

③ 每个件最容易烧的原因 → 怎么防

件 | 烧的原因 | 怎么防
TB6612 | VM/VCC 接反；XL6009 没调压直接高压进 VM；电机长时间堵转过 流过热 | VM≠VCC；先调 5.5V 再接；固件「高电流+编码器不 动」拉低 STBY 急停
开发板 I²C 脚 | MAX17048 的 VLogic 接了电池 → 4.2V 灌进 I²C | VLogic 只接 3V3
QMI8658 / BH1750 | VCC 接了 5V 或电池 | VCC 只接 3V3
电池 | 输出短路 → 瞬间大电流（可能起火） | 上电前查短路；TP4056 的 3A 保护兜底，但别赌；接 头别裸露
XL6009 | 输出短路；输入 3.7V 属超下限、长时间大电流发热 | 查短路；摸温度；电机别长时间堵转；散热不良就降 负载
电机 | 没调压被高压冲；长时间堵转过热 | 先调 5.5V；堵转急停；MP 级低堵转电机

有条件最稳：第一次给电机轨上电，用带限流的实验电源把限流设到 ~0.5A 先试（有短路会限流不烧件）；没有就电池正极串一个 2~3A 保险丝当一次性兜底。

## 备用套装（保险包，跟主单一起下）

就一个发货周期，按「最容易烧 / 最容易搞错 / 消耗快」把备件一起买了，省得烧一个等一周。每件都对到前面分析的具体风险。

① 易烧的主力件——直接备（都便宜）

备件 | 数量 | ≈价 | 防哪个风险 / 为什么备
TB6612FNG 模块 | 2 | ¥10 | 最容易烧：VM/VCC 接反、XL6009 没调压高压进 VM、电机堵转——而且是驱动主 力，烧了整车停
QMI8658 模块 | 1 | ¥15 | 接错 5V/静电易坏；万一 DOA 有得换（IMU 是关键件）
GY-302 BH1750 | 1 | ¥5 | 便宜，接错/坏了直接换
INA219 模块 | 1 | ¥8 | 同上；还在电机轨高边，受冲击大
N20 编码电机(MP级) | 1 | ¥25 | 运动件最易坏：堵转过热、没调压被高压冲；三个同款留一个备
XL6009 升压模块 | 1 | ¥4 | 输出短路/3.7V 超下限发热易坏；电机轨命脉
总开关 / TP4056 | 各1 | ¥5 | 开关触点、TP4056 的 Type-C 口/焊点都易坏，便宜备

② 主动保护小件——加这些更难烧（强烈建议）

件 | 数量 | ≈价 | 防哪个风险
I²C 电平转换模块 (TXS0108E / 4路) | 1 | ¥5 | 防 I²C 过压烧开发板脚：MAX17048 VLogic 接错、或不小心混入 5V I²C 模块时，转换 模块挡在中间救开发板
保险丝 + 保险丝座 (玻璃管 5×20 或自恢复 PTC) | 几个 | ¥5 | 电池短路兜底：串电池正极，短路时先断保险丝而不是烧电池/线。具体参数见下表 ↓
电解电容 470µF/1000µF 16V | 各5 | ¥5 | 升压输出 / 电机轨 bulk，防电机启停、WiFi6 尖峰把轨拉跌→重启
电阻包(2.2k/4.7k/10k/220Ω) | 1包 | ¥5 | I²C 上拉不够时补、LED 限流、各种临时
肖特基二极管(SS34/1N5819) | 几个 | ¥3 | 防反接/续流应急

↑ 保险丝具体参数（串在电池正极第一段：电池+ → 保险丝 → TP4056/总开关）：

参数 | 要求 | 为什么
额定电流 | 玻璃管 T3.15A~4A 慢断(T)型； 自恢复 PTC：保持 Ihold≈3A / 动作 Itrip≈6A | 常态电机 ~1.2A、启动/堵转峰值 ~3A 不能误断；短路 10A+ 要 立断。所以选 3~4A 这档、且"慢断"扛得住启动尖峰
额定电压 | ≥6V 即可（不是瓶颈） | 电池侧最高才 4.2V；常见玻璃管标 125/250V、PTC 选 ≥6V， 都远够
分断能力 | 玻璃管选标 ≥35A 分断 | 1S 锂电短路瞬间能放几十 A，分断能力不够的保险丝会被电弧 烧穿而不是断开
规格/封装 | 玻璃管 5×20mm + 配套保险丝座（易换）；或插件/贴片自 恢复 PTC | 玻璃管一次性、短路必断最干净；PTC 自恢复省得换，但保持 电流前有 ~2× 缓冲
买几个 | 玻璃管 T3.15A 与 T4A 各 3~5 个 + 座 1~2 | 一次性件，断了要换；两个值都备好按实测电流选

③ 替代方案件——主件不行时顶上（每样 1 个）

备用件 | 数量 | ≈价 | 什么时候用它
DRV8833 模块 | 1 | ¥4 | TB6612 不够/想要自带过流过温保护时换（脚位接近，固件方向逻辑略改）
MPU6050 模块(GY-521) | 1 | ¥3~8 | 替 QMI8658 的便宜备用：6 轴 I²C、ESP-IDF 例程最多最好找。缺点：更老/漂移大、 无硬件 Tap 引擎——碰撞/抬起得固件读原始加速度自己算（应急够用）。注：①里已 备一颗同款 QMI8658 是首选备用；这颗是"换个类型"的兜底
SX1308 / MT3608 升压 | 1 | ¥2 | XL6009 在 3.7V 吃力时换；或决定电机直接吃电池不升压时就都不用
杜邦线(母-母为主) | 2套 | ¥20 | 消耗品，反复插拔损耗快，多备
JST 端子线 PH2.0 + XH2.54(公母) | 各几条 | ¥10 | 防接头搞错(PH2.0≠XH2.54)，两种都备好转接
热缩管 + 绝缘胶带 | 1 | ¥10 | 消耗品

两条提醒： ① 开发板不可备（就一块、最贵 ESP32-P4-WIFI6）——所以它最该小心：用电脑 USB 供电已经把它保护得很好，剩下唯一真风 险是 I²C 被灌高压，上面 ②的电平转换模块就是专门救它的，强烈建议装。 ② MAX17048(¥30)不必备：贵，且不在易烧链上；真坏了用「2 个电阻分压 → 开发板 ADC 读电池电压」临时顶（粗略电量，~¥0）。
保险包合计约 ¥150~180，相对"烧一个等一周"很值。

## 电气验证（系统级）

※ 架构已变更（2026-06）：现在开发板由电脑 USB 供电、电池只带电机。所以下面"功率/电流预算"里关于「开发板升压不够 / 电池总电流 ~3.5A / TP4056 会跳闸」的分析是旧的全电池方案最坏情况，现已不适用——新方案电池侧只剩电机 ~0.75A(常态)，TP4056 和电池压力大 减。电压兼容/I²C 地址/GPIO/ngspice I²C 仿真这几节仍然有效。

模块是黑盒、跑不了器件级 SPICE，下面做的是系统级电气验证（电压兼容 / 功率电流预算 / 续航 / I²C 地址 / GPIO 预算）+ 一处真仿真（I²C 长线上升时间， ngspice）。

① 电压兼容矩阵

模块/件 | 供电需求 | 接的轨 | 判定
IMU ICM-42688-P / QMI8658 | 1.71–3.6V / 1.71–3.6V | 3V3 | ✅
BH1750FVI | 2.4–3.6V | 3V3 | ✅
INA219 | 3–5.5V（Vin± 可测到 26V） | 3V3（Vin± 串 5.5V 高边） | ✅
MAX17048 | 2.5–4.5V | VBAT 直供 | ✅
TB6612FNG | VCC 2.7–5.5V / VM 2.5–13.5V | VCC=3V3 · VM=5.5V | ✅ (VCC≠VM,别插反)
N20 电机 / 编码器 | 电机 6V额定 · 编码器 3.3–5V | 电机=5.5V · 编码器=3V3 | ✅ 6V件跑5.5V约-8%可忽略

逻辑电平全 3V3，与开发板 IO 一致 ✅。唯一易错：TB6612 的 VCC(逻辑)=3V3、VM(功率)=5.5V 是两个脚，最容易插反烧件。

② 功率/电流预算 + 续航

轨 | 源能力 | 负载估算 | 结论
3V3 逻辑 | 开发板 LDO 余量（需查， 常 ≥100mA） | 编码器 3×~8mA + 传感器 ~3mA + TB6612 逻辑 ~5mA ≈ 32mA | ✅ 大概率够；下单后实测开发板 3V3 余量，不足则 VSYS 旁挂 AMS1117 单独供 3V3
5.5V 电机轨 | MT3608#2 输出 ≈1.2A(2A 是开关限流；5.5V 输出 ≈Isw·3.7/5.5·η) | 常态行进 3×90mA≈0.27A；全堵转 3×400mA=1.2A(实测电机) | ✅ 常态够(约 2× 余量)；⚠️ 多电机同堵转远超能力 会拉垮轨（MT3608 限流=粗保护），靠固件堵转急停 +编码器兜底
5V VSYS | MT3608#1 输出 ≈1.3A(2A 开关限流，5V 输出实约 1.3A) | P4-WIFI6 峰值(WiFi6发射+算力) ~1.3– 1.5A@5V | ⚠️偏弱/不够！ 原 IP5306 是 2.1A 升压。MT3608 5V 实际只出 ~1.3A < P4 峰值 → VSYS 这路必须换 XL6009/SX1308(4A，5V 可出 ~2.6A) 或 2A+ 专用 升压
VBAT/续航 | 3000mAh@3.7V=11.1Wh； TP4056 充 1A≈3.3h | 待机 ~1.2W；运动峰值 ~4W | ✅ 待机 ~9h、连续运动 ~2.5–3h（与 docs 一致）

③ I²C1 地址表（挂同一总线，查冲突）

设备 | 7-bit 地址 | 说明
BH1750FVI | 0x23 | ADDR 悬空/低；拉高=0x5C
MAX17048 | 0x36 | 固定
INA219 | 0x40 | A0/A1 低；可改址
QMI8658（若替代 ICM 走 I²C） | 0x6B | SA0 高；或 0x6A

✅ 四地址互不冲突（0x23/0x36/0x40/0x6B）。ICM-42688-P 走 SPI 时不占 I²C。

④ GPIO 预算

用脚：3 PWM + 6 IN + 1 STBY + 6 编码器 + IMU(SPI 5 脚) + I²C 2 + ADC 1 = 24 个；可用池 ≈ 28（避开 IO7/8 音频I²C0、IO9-13/53 音频I²S、IO39-44 microSD、调试 脚）→ ✅ 够用，余 ~4。换 QMI8658(I²C) 则释放 SPI 4 脚、用脚降到 20，更宽裕。

⑤ 仿真：I²C 长线上升时间（ngspice，验证 BH1750 贴壳引线）

开漏释放 → 上拉 Rp 对总线电容 Cb（含 40cm 杜邦引线）充电，测 10–90% 上升时间，对照 I²C 规范（快速模式≤300ns / 标准模式≤1000ns）：

场景 | Rp | Cb | t_rise(10–90%) | 判定
板上(无引线) | 4.7k | 30pF | 310 ns | 标准✓ / 快速✗
40cm引线·默认上拉 | 4.7k | 80pF | 826 ns | 标准✓ / 快速✗
40cm引线·改 2.2k | 2.2k | 80pF | 387 ns | 标准✓(余量足) / 快速✗
长/捆扎最坏 | 2.2k | 150pF | 725 ns | 标准✓ / 快速✗
40cm引线·1.5k | 1.5k | 80pF | 264 ns | 快速✓+标准✓

结论：BH1750 贴壳 40cm 引线 → 用 100kHz + 2.2k 上拉（387ns，远在标准 1000ns 内，最稳）；若一定要 400kHz 快速模式 → 用 1.5k 上拉（264ns<300ns，灌电流 3.3V/1.5k=2.2mA 仍在 BH1750 与 I²C 规范的 3mA 之内）。默认 4.7k 在长线上跑 400kHz 会超时。

电气验证总结：电压兼容全过；I²C 四地址不冲突；GPIO 24/28 够用；续航与 docs 一致。唯一要改的硬点： 5V VSYS 升压用 MT3608 实际 只出 ~1.3A，不够 P4-WIFI6 ~1.5A 峰值 → VSYS 这路换 XL6009/SX1308(4A 级)（电机轨那片 MT3608 维持 5.5V 不变）。次级提醒：MT3608 的 2A 是开关限流、升压后实际输出打折；多电机同堵转会拉垮电机轨（属预期，靠固件急停）；下单后实测开发板 3V3 余量。

NanoSoul 应急 SKU BOM · 模块/规格经厂商 datasheet、立创开发板 wiki、Waveshare、Adafruit 多源核对 · GPIO 取自 pcb/circuit/pins.py · I²C 上升时间为 ngspice 实仿 · 不含未经核实的 LCSC C 号(立创无成品模块) · 下单按淘宝关键词核对实物图、间距与电压(尤其电池 PH2.0、IMU 是否 3.3V 直供、IP5306 是否真 I²C)。

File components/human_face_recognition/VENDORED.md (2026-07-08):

# vendored: espressif/human_face_recognition 0.3.2

来源: https://github.com/espressif/esp-dl `models/human_face_recognition`
commit `f43b41fd533da882382f9cd3ef305c829c138189`（= 我们锁定的 human_face_detect 0.5.0 的发布 commit，API 与 managed esp-dl 3.3.0 对齐）。

**为什么不走组件注册表**：已发布的 0.3.2 归档 manifest 钉死 `human_face_detect ~0.4.1`，
与本仓库锁定的 0.5.0 版本求解无解（repo 里该 commit 的 manifest 已改成 ~0.5.0，但归档没重发）。
上游修发布后可删掉本目录、改回 `idf_component.yml` 注册表依赖。

改动（相对上游原样）：
- 删 `idf_component.yml`（避免再次卷入版本求解；依赖走 CMake `REQUIRES`）。
- 只保留 P4 的 MFN 模型（`models/p4/human_face_feat_mfn_s8_v1.espdl`，1.27MB）；
  MBF（3.4MB）与 S3 模型未拷。
- 已知上游 bug：`recognize()/enroll()` 多脸时 `std::max_element` 比较器方向反了，
  实际选到**最小**脸——调用方（components/vision）只传单脸列表规避。

模型部署（`CONFIG_HUMAN_FACE_FEAT_MODEL_IN_SDCARD=y`）：
把 `models/p4/human_face_feat_mfn_s8_v1.espdl` 拷到 SD 卡 **`model/p4/`** 目录下
（目录名由 sdkconfig.defaults 的 `CONFIG_HUMAN_FACE_FEAT_MODEL_SDCARD_DIR="model/p4"` 决定，
与现役 SD 卡的既有目录保持一致）。

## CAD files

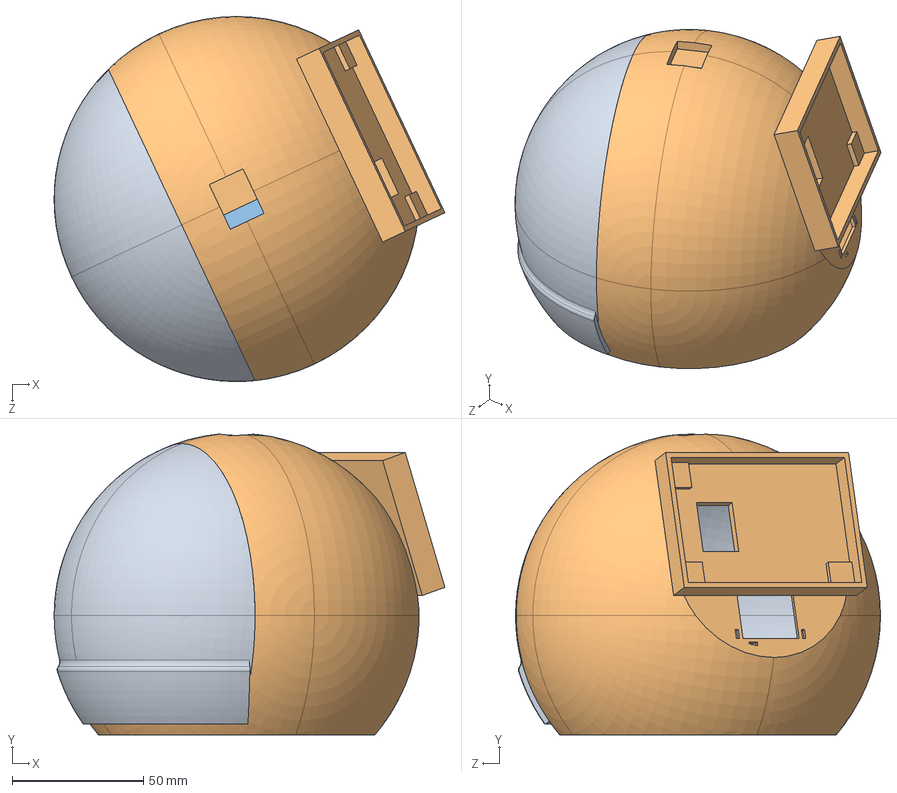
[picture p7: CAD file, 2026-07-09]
enclosure/models/装配体.SLDASM
148.8 x 114.5 x 139.0 mm
地盘1
skus
case

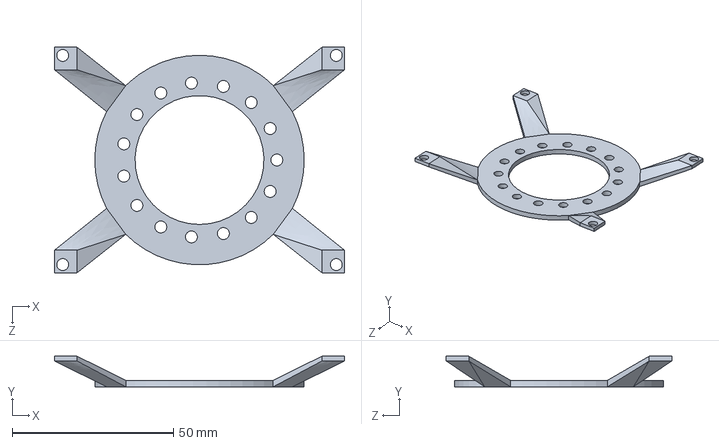
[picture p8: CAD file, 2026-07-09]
enclosure/models/boardsupporter.SLDPRT
90.0 x 9.50 x 70.0 mm

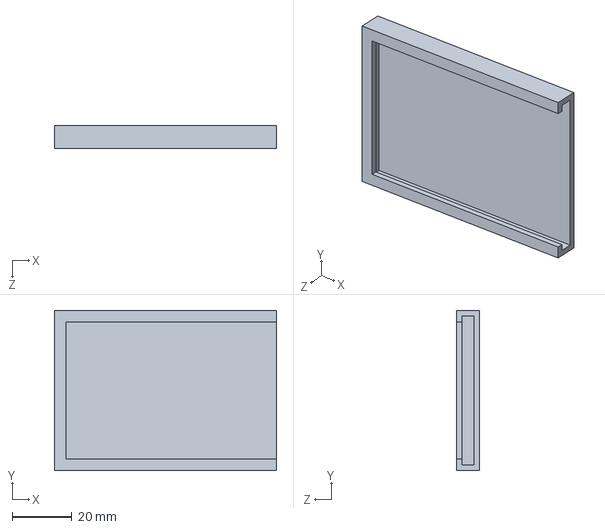
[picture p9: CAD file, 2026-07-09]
enclosure/models/ScreenShell.SLDPRT
74.3 x 53.6 x 7.60 mm

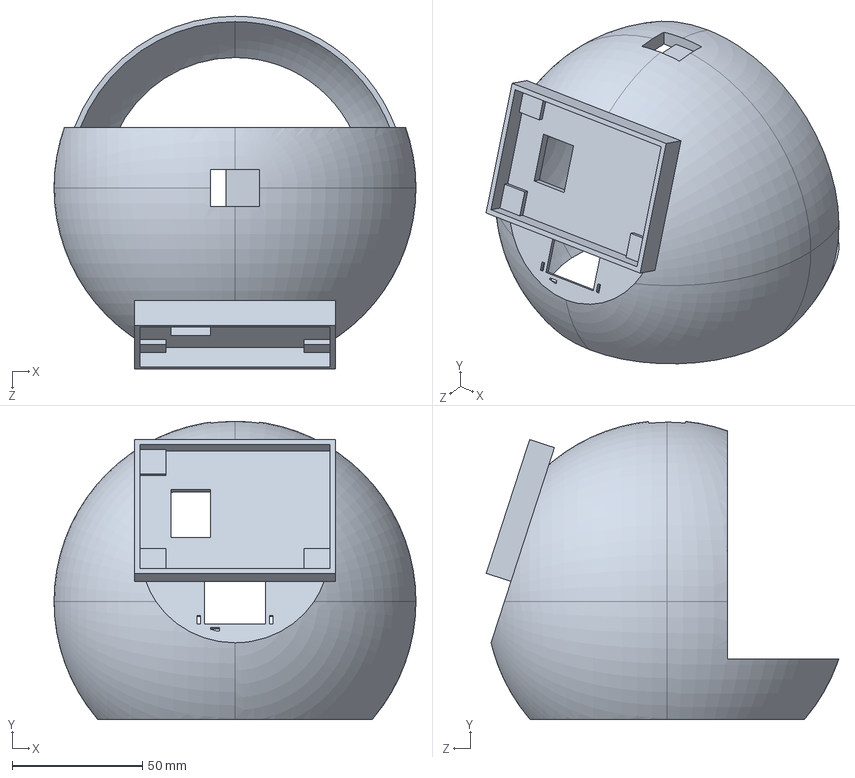
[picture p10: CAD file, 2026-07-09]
enclosure/models/body.SLDPRT
139.0 x 114.5 x 135.4 mm

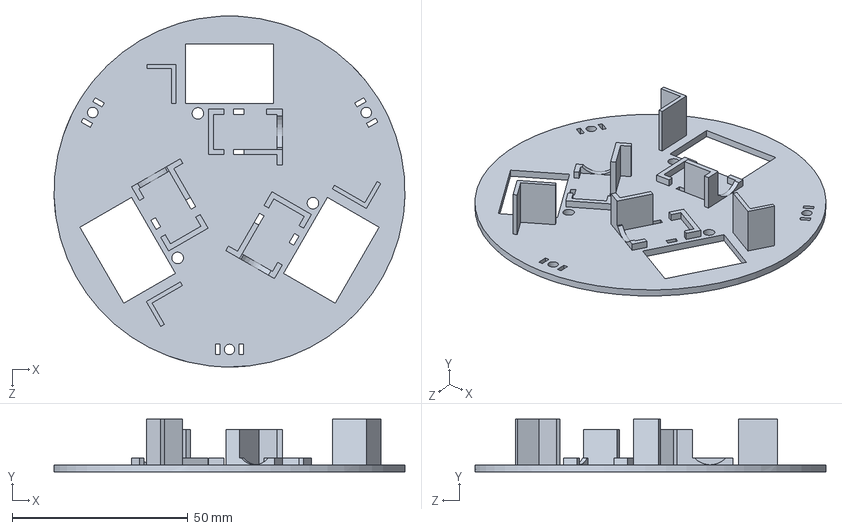
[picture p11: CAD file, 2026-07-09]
enclosure/models/地盘1.SLDPRT
100.0 x 15.0 x 100.0 mm

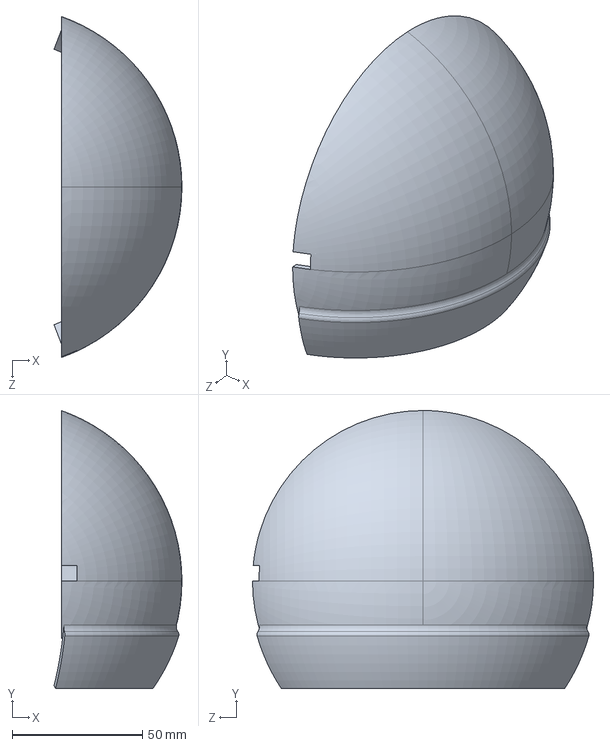
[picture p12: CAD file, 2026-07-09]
enclosure/models/case.SLDPRT
49.2 x 106.8 x 131.1 mm

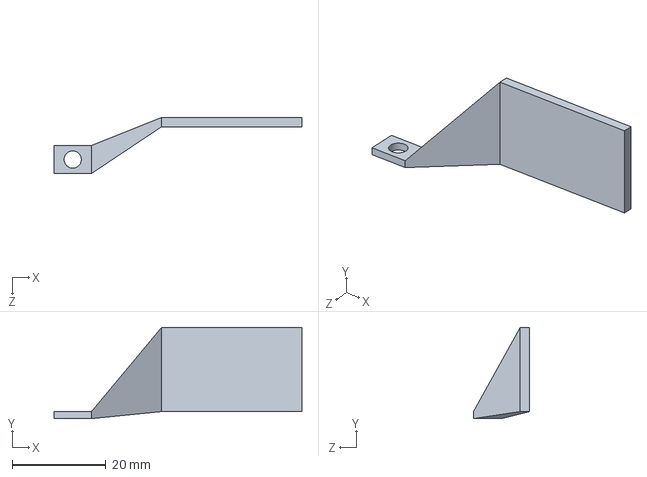
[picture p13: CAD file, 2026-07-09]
enclosure/models/supporter.SLDPRT
53.0 x 19.5 x 12.0 mm

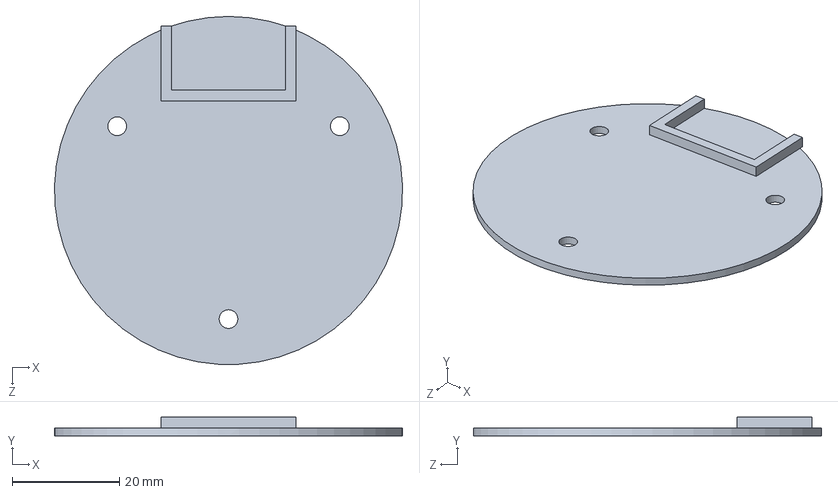
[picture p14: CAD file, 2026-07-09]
enclosure/models/skus.SLDPRT
65.0 x 3.50 x 65.0 mm

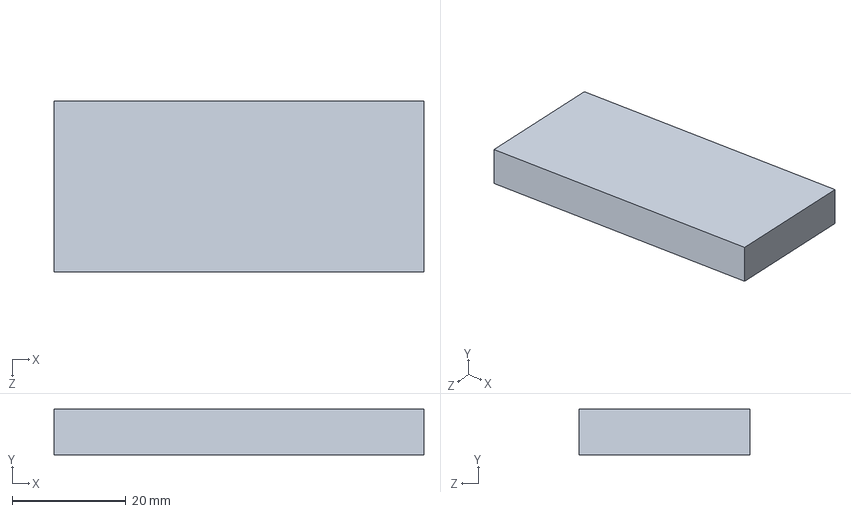
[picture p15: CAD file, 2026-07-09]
enclosure/models/power.SLDPRT
65.0 x 8.00 x 30.0 mm

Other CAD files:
enclosure/models/stls/boardsupporter.STL
enclosure/models/stls/body.STL
enclosure/models/stls/case.3mf
enclosure/models/stls/case.STL
enclosure/models/stls/supporter.STL
enclosure/models/stls/地盘1.STL

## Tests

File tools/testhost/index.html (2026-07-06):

NanoSoul 测试台 未连接 连 WebSocket 连串口 (Chromium) 断开 急停 ESTOP 解除故障

## 反应观察 (state)

—

emotion—

behavior—

mood E / S—

duty—

face—

net—

llm / voice—

heap—

## 硬件清单 (hwinfo)

刷新 hwinfo

## 刺激注入

sense 速率 关10 2050Hz

override 通道

事件直注 inject_event

## 电机测试

M duty ms RUN 全停

teleop 点动 (需 motion.enabled)

前 ↑后 ↓ 左 ←右 → 转 ↻转 ↺

enc count—

enc rpm—

## 实时曲线 & 量程 (sense)

复位统计 导出量程 JSON 导出量程 CSV sense: 关

## 场景脚本 (注入→反应)

## 自检矩阵

跑一轮 selftest

## 事件 / 日志时间轴

清空 快照 (WS)

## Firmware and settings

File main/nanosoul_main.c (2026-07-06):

// NanoSoul 整机固件入口。
// Boot mode: an IO48-to-GND strap at boot forces TEST mode; otherwise the
// Kconfig NANOSOUL_MODE choice decides:
//   FACE     — emote face + debug HUD (wired from Phase A onward).
//   SELFTEST — auto-loop diagnostics; JSON matrix to serial.
//   TEST     — full runtime + test services (override/motor_test/serial link).
//   TESTPANEL— legacy LVGL three-motor bring-up panel.
// ESP-IDF v5.5.2 / ESP32-P4. flash/monitor 由持板者本地手动跑（板外纪律）。
#include "driver/gpio.h"
#include "esp_chip_info.h"
#include "esp_idf_version.h"
#include "esp_log.h"
#include "nvs_flash.h"
#include "freertos/FreeRTOS.h"
#include "freertos/task.h"

#include "app_face.h"
#include "app_selftests.h"
#include "app_testmode.h"
#include "esp_netif.h"
#include "ns_config.h"
#include "sd_storage.h"
#include "selftest.h"
#include "simsense.h"
#include "telemetry.h"

#if CONFIG_NANOSOUL_MODE_TESTPANEL
#include "display.h"
#include "test_app.h"
#endif

// Boot strap: short IO48 to GND to force TEST mode (internal pull-up; conflict
// fallback = IO33 — change only this one line). Read once at boot, then release.
#define TEST_STRAP_GPIO GPIO_NUM_48

static const char *TAG = "nanosoul";

static bool strap_test_mode(void)
{
    gpio_config_t io = {
        .pin_bit_mask = 1ULL << TEST_STRAP_GPIO,
        .mode = GPIO_MODE_INPUT,
        .pull_up_en = GPIO_PULLUP_ENABLE,
        .pull_down_en = GPIO_PULLDOWN_DISABLE,
        .intr_type = GPIO_INTR_DISABLE,
    };
    gpio_config(&io);
    vTaskDelay(pdMS_TO_TICKS(10));
    int low = 0;
    for (int i = 0; i < 5; i++) {
        low += (gpio_get_level(TEST_STRAP_GPIO) == 0);
        vTaskDelay(pdMS_TO_TICKS(1));
    }
    gpio_reset_pin(TEST_STRAP_GPIO);
    return low >= 4;   /* strapped to GND */
}

static const char *kconfig_mode_name(void)
{
#if CONFIG_NANOSOUL_MODE_FACE
    return "FACE";
#elif CONFIG_NANOSOUL_MODE_SELFTEST
    return "SELFTEST";
#elif CONFIG_NANOSOUL_MODE_TEST
    return "TEST";
#else
    return "TESTPANEL";
#endif
}

// Bring up the always-on core: NVS, telemetry hub, selftest registry, SD card
// + config. Runs in every mode.
static void init_common(void)
{
    esp_err_t err = nvs_flash_init();
    if (err == ESP_ERR_NVS_NO_FREE_PAGES || err == ESP_ERR_NVS_NEW_VERSION_FOUND) {
        ESP_ERROR_CHECK(nvs_flash_erase());
        ESP_ERROR_CHECK(nvs_flash_init());
    }

    ESP_ERROR_CHECK(telemetry_init());
    ESP_ERROR_CHECK(selftest_init());
    ESP_ERROR_CHECK(simsense_init());   /* 传感覆盖层：所有模式常驻，非测试时整表空 */

    /* Bring up the TCP/IP stack unconditionally so the companion WS server can
     * start even when no Wi-Fi is configured (netlink skips it when offline). */
    ESP_ERROR_CHECK(esp_netif_init());

    if (sd_storage_mount(SD_MOUNT_POINT) != ESP_OK) {
        ESP_LOGW(TAG, "SD not mounted; continuing on default config");
    }
    ns_config_init(NS_CONFIG_PATH); // loads defaults even without a card

    app_selftests_register();
}

void app_main(void)
{
    esp_chip_info_t chip;
    esp_chip_info(&chip);

    bool strap = strap_test_mode();
#if CONFIG_NANOSOUL_MODE_TEST
    bool test_mode = true;             // Kconfig forces TEST (board-off, no jumper)
#else
    bool test_mode = strap;            // strap overrides the Kconfig default
#endif

    ESP_LOGI(TAG, "NanoSoul boot — kconfig=%s strap=%d -> %s, ESP-IDF %s, target %s, %d core(s)",
             kconfig_mode_name(), strap, test_mode ? "TEST" : kconfig_mode_name(),
             esp_get_idf_version(), CONFIG_IDF_TARGET, chip.cores);

    init_common();

    if (test_mode) {
        app_test_run();                // full runtime + test services (docs/13)
        return;
    }

#if CONFIG_NANOSOUL_MODE_TESTPANEL
    ESP_ERROR_CHECK(display_init());   // ST7701 + LVGL
    ESP_ERROR_CHECK(test_app_start()); // 电机/编码器/电流 + 自动循环 + 面板
#elif CONFIG_NANOSOUL_MODE_SELFTEST
    app_face_run(true);   // full runtime + auto-loop diagnostics
#else /* FACE */
    app_face_run(false);  // emote face + debug HUD (product/demo)
#endif
}

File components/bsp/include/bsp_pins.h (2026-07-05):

#pragma once
/*
 * NanoSoul board-fixed pin map — Waveshare ESP32-P4-WIFI6.
 *
 * These are the *on-board* resources of the dev board itself (TF card, board
 * I2C0, audio codec, MIPI-DSI display, MIPI-CSI camera). They are hard-wired on
 * the module and cannot be moved. Values verified against the working
 * /home/gxxl/testP4 bring-up and Waveshare wiki.
 *
 * The *external* (no-PCB prototype) pins for motors / encoders / INA219 / IMU /
 * BH1750 live in the drv_* modules and CLAUDE.md「固件」节 — do not duplicate
 * them here.
 */

#include "driver/gpio.h"

/* ---------- TF card: fixed pins, on-board 10k pullups, mounted as SDSPI ---------- */
#define BSP_SD_CLK      GPIO_NUM_43
#define BSP_SD_CMD      GPIO_NUM_44   /* = SPI MOSI */
#define BSP_SD_D0       GPIO_NUM_39   /* = SPI MISO */
#define BSP_SD_D1       GPIO_NUM_40
#define BSP_SD_D2       GPIO_NUM_41
#define BSP_SD_D3       GPIO_NUM_42   /* = SPI CS   */
#define BSP_SD_LDO_CHAN 4             /* LDO_VO4 powers the SD IO rail */

/* ---------- Board I2C0 (ES8311 + FT6x36 touch + OV5647 SCCB) ---------- */
#define BSP_I2C0_PORT   0
#define BSP_I2C0_SCL    GPIO_NUM_8
#define BSP_I2C0_SDA    GPIO_NUM_7
#define BSP_I2C0_FREQ   100000

/* ---------- ES8311 codec + NS4150B amp (I2S0) ---------- */
#define BSP_I2S_PORT    0
#define BSP_I2S_MCLK    GPIO_NUM_13
#define BSP_I2S_BCLK    GPIO_NUM_12
#define BSP_I2S_WS      GPIO_NUM_10
#define BSP_I2S_DOUT    GPIO_NUM_9    /* ESP TX -> codec DSDIN (playback) */
#define BSP_I2S_DIN     GPIO_NUM_11   /* codec ASDOUT -> ESP RX (record)  */
#define BSP_PA_CTRL     GPIO_NUM_53   /* NS4150B enable, active HIGH       */
#define BSP_ES8311_ADDR 0x18

/* ---------- MIPI-DSI display (WLK2802, ST7701S 2.8" 480x640 portrait) ---------- */
#define BSP_LCD_H_RES           480
#define BSP_LCD_V_RES           640
#define BSP_LCD_DSI_LANES       1
#define BSP_LCD_DSI_LANE_MBPS   700
#define BSP_LCD_DPI_CLK_MHZ     25

/* ---------- MIPI-CSI camera (OV5647, SCCB shares board I2C0) ---------- */
#define BSP_CAMERA_SCCB_ADDR    0x36

/* ---------- Shared MIPI DPHY LDO rail (DSI + CSI both use VO3 @2.5V) ---------- */
#define BSP_MIPI_DPHY_LDO_CHAN  3
#define BSP_MIPI_DPHY_LDO_MV    2500

/* ---------- Touch (FT6x36 on board I2C0) ---------- */
#define BSP_TOUCH_ADDR          0x38

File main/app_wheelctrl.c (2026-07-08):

#include "app_wheelctrl.h"

#include <math.h>
#include <string.h>

#include "esp_check.h"
#include "esp_log.h"
#include "esp_timer.h"
#include "freertos/FreeRTOS.h"
#include "freertos/task.h"

#include "drv_encoder.h"
#include "drv_motor.h"
#include "motion.h"
#include "ns_config.h"
#include "odom.h"
#include "telemetry.h"

static const char *TAG = "wheelctrl";

#define WC_PERIOD_MS   20        /* 50Hz：满速 ~150 计数/拍，10% 速度 ~15 计数/拍 */

/* 积分项对输出的最大贡献（duty counts）。前馈担主力，积分只修 kv 标定残差
 * （120 duty ≈ 满速下 12% 的修正权限）；夹太松会在斜坡期灌满导致大超调。
 * 注意 pid_ctrl 的 max_integral 夹的是【误差累计和，rpm·拍】：换算 = 上限/ki。 */
#define WC_TRIM_I_MAX  120.0f

static pid_ctrl_parameter_t wc_pid_param(float kp, float ki, float kd)
{
    float max_sum = (ki > 1e-6f) ? WC_TRIM_I_MAX / ki : 1e9f;
    return (pid_ctrl_parameter_t){
        .kp = kp, .ki = ki, .kd = kd,
        .max_output = MOTOR_DUTY_MAX,
        .min_output = -MOTOR_DUTY_MAX,
        .max_integral = max_sum,
        .min_integral = -max_sum,
        .cal_type = PID_CAL_TYPE_POSITIONAL,
    };
}

/* ---------------- 纯控制器（单轮） ---------------- */

esp_err_t wc_state_init(wc_state_t *st, const wc_gains_t *g, float kp, float ki, float kd)
{
    (void)g;
    memset(st, 0, sizeof(*st));
    pid_ctrl_config_t cfg = { .init_param = wc_pid_param(kp, ki, kd) };
    return pid_new_control_block(&cfg, &st->pid);
}

void wc_state_deinit(wc_state_t *st)
{
    if (st->pid) {
        pid_del_control_block(st->pid);
        st->pid = NULL;
    }
}

void wc_reset(wc_state_t *st)
{
    st->sp = 0.0f;
    st->meas = 0.0f;
    if (st->pid) {
        pid_reset_ctrl_block(st->pid);
    }
}

float wc_step(wc_state_t *st, const wc_gains_t *g, float sp_target, float meas_inst, float dt_s)
{
    /* 死区看目标值（斜坡中间值低于阈值是正常的起步过程，不能据此清零卡死）；
     * 目标进死区时把斜坡目标改成 0，平滑滑到停。 */
    bool sp_small = fabsf(sp_target) < g->deadband_rpm;

    /* 设定值斜坡（每轮同速率限幅；意图级缓入缓出由原语层负责，这里是安全包络） */
    float dmax = g->ramp_rpm_per_s * dt_s;
    float d = (sp_small ? 0.0f : sp_target) - st->sp;
    if (d > dmax) d = dmax;
    if (d < -dmax) d = -dmax;
    st->sp += d;

    /* 测量 EMA（50Hz 差分的量化噪声，低速端 ±1 计数 ≈ ±107 rpm 电机轴） */
    st->meas += g->meas_alpha * (meas_inst - st->meas);

    if (sp_small && fabsf(st->sp) < g->deadband_rpm) {
        /* 稳定停下：零输出 + 清积分；meas 继续跟踪（滑行中重新起步不失真） */
        st->sp = 0.0f;
        if (st->pid) {
            pid_reset_ctrl_block(st->pid);
        }
        return 0.0f;
    }

    float trim = 0.0f;
    if (st->pid) {
        pid_compute(st->pid, st->sp - st->meas, &trim);
    }
    float out = g->ks * (st->sp > 0 ? 1.0f : -1.0f) + g->kv * st->sp + trim;
    if (out > MOTOR_DUTY_MAX) out = MOTOR_DUTY_MAX;
    if (out < -MOTOR_DUTY_MAX) out = -MOTOR_DUTY_MAX;
    return out;
}

/* ---------------- 三轮任务 ---------------- */

static wc_gains_t s_gains[MOTOR_COUNT];
static wc_state_t s_wc[MOTOR_COUNT];
static float      s_rpm_max = 15000.0f;

/* 目标设定值：apply/override 写、控制任务读。都是任务上下文（motion 的
 * esp_timer 回调跑在 esp_timer 任务里），自旋锁护 12 字节拷贝足够。 */
static portMUX_TYPE  s_mux = portMUX_INITIALIZER_UNLOCKED;
static float         s_target[MOTOR_COUNT];
static volatile bool s_active;          /* 有驱动权才碰 motor_set */
static int64_t       s_override_end_us; /* >now 时 s_target 来自 override */

static bool           s_running;
static bool           s_drive;                /* closed_loop：false=只测量+里程计 */

/* 里程计：任务独占写；reset 请求用标志位跨任务传递（避免半步撕裂） */
static odom_geom_t   s_geom;
static odom_pose_t   s_pose;
static volatile bool s_odom_reset_req;

void wheel_ctrl_odom_reset(void) { s_odom_reset_req = true; }
bool wheel_ctrl_closed_loop(void) { return s_running && s_drive; }

void wheel_ctrl_apply(const int16_t cmd[3])
{
    if (!s_drive) {
        return;   /* 只测量模式不该被注册为 apply 桥；防御 */
    }
    float scale = s_rpm_max / (float)MOTION_DUTY_MAX;
    portENTER_CRITICAL(&s_mux);
    if (esp_timer_get_time() >= s_override_end_us) {   /* override 期间 motion 让位 */
        for (int i = 0; i < MOTOR_COUNT; i++) {
            s_target[i] = (float)cmd[i] * scale;
        }
        s_active = true;
    }
    portEXIT_CRITICAL(&s_mux);
}

void wheel_ctrl_override_sp(const float sp_rpm[3], uint32_t ms)
{
    portENTER_CRITICAL(&s_mux);
    for (int i = 0; i < MOTOR_COUNT; i++) {
        float v = sp_rpm[i];
        if (v > s_rpm_max) v = s_rpm_max;
        if (v < -s_rpm_max) v = -s_rpm_max;
        s_target[i] = v;
    }
    s_override_end_us = esp_timer_get_time() + (int64_t)ms * 1000;
    s_active = true;
    portEXIT_CRITICAL(&s_mux);
}

void wheel_ctrl_halt(void)
{
    portENTER_CRITICAL(&s_mux);
    memset((void *)s_target, 0, sizeof(s_target));
    s_override_end_us = 0;
    s_active = false;
    portEXIT_CRITICAL(&s_mux);
    for (int i = 0; i < MOTOR_COUNT; i++) {
        wc_reset(&s_wc[i]);
    }
    if (s_running) {
        motor_stop_all();
    }
}

void wheel_ctrl_pid_set(float kp, float ki, float kd)
{
    pid_ctrl_parameter_t p = wc_pid_param(kp, ki, kd);
    for (int i = 0; i < MOTOR_COUNT; i++) {
        if (s_wc[i].pid) {
            pid_update_parameters(s_wc[i].pid, &p);
        }
    }
    ESP_LOGI(TAG, "pid_set kp=%.4f ki=%.4f kd=%.4f", kp, ki, kd);
}

bool wheel_ctrl_running(void) { return s_running; }
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

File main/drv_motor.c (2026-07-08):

#include "drv_motor.h"

#include "driver/gpio.h"
#include "driver/ledc.h"
#include "esp_check.h"
#include "esp_log.h"

static const char *TAG = "motor";

#define PWM_MODE     LEDC_LOW_SPEED_MODE   // P4 只有低速域
#define PWM_TIMER    LEDC_TIMER_0          // 三路共用一个 20kHz 定时器
#define PWM_RES      LEDC_TIMER_10_BIT
#define PWM_FREQ_HZ  20000                 // ~20kHz，超声、避开可闻噪声

typedef struct {
    gpio_num_t pwm, in1, in2, stby;
    ledc_channel_t ch;
} motor_cfg_t;

// 引脚真值源 docs/BOARD_MAPPING.md（杜邦接，可改；改了同步该文件）。
// STBY 两片分开：M0/M1 桥=IO51，M2 桥=IO52（实物杜邦不够没并到一起）。
static const motor_cfg_t s_motors[MOTOR_COUNT] = {
    { GPIO_NUM_2,  GPIO_NUM_3,  GPIO_NUM_4,  GPIO_NUM_51, LEDC_CHANNEL_0 },  // M0
    { GPIO_NUM_5,  GPIO_NUM_24, GPIO_NUM_25, GPIO_NUM_51, LEDC_CHANNEL_1 },  // M1
    { GPIO_NUM_26, GPIO_NUM_27, GPIO_NUM_32, GPIO_NUM_52, LEDC_CHANNEL_2 },  // M2
};

esp_err_t motors_init(void)
{
    // 所有 IN1/IN2 + 所有 STBY 配成输出（位掩码自动去重）
    uint64_t mask = 0;
    for (int i = 0; i < MOTOR_COUNT; i++) {
        mask |= (1ULL << s_motors[i].in1) | (1ULL << s_motors[i].in2) | (1ULL << s_motors[i].stby);
    }
    gpio_config_t io = {
        .pin_bit_mask = mask,
        .mode = GPIO_MODE_OUTPUT,
        .pull_up_en = GPIO_PULLUP_DISABLE,
        .pull_down_en = GPIO_PULLDOWN_DISABLE,
        .intr_type = GPIO_INTR_DISABLE,
    };
    ESP_RETURN_ON_ERROR(gpio_config(&io), TAG, "gpio");

    // 1 个共享 20kHz 定时器
    ledc_timer_config_t tcfg = {
        .speed_mode = PWM_MODE,
        .duty_resolution = PWM_RES,
        .timer_num = PWM_TIMER,
        .freq_hz = PWM_FREQ_HZ,
        .clk_cfg = LEDC_AUTO_CLK,
    };
    ESP_RETURN_ON_ERROR(ledc_timer_config(&tcfg), TAG, "ledc timer");

    for (int i = 0; i < MOTOR_COUNT; i++) {
        gpio_set_level(s_motors[i].in1, 0);
        gpio_set_level(s_motors[i].in2, 0);
        gpio_set_level(s_motors[i].stby, 0);   // 上电先禁用，等显式 enable
        ledc_channel_config_t ccfg = {
            .gpio_num = s_motors[i].pwm,
            .speed_mode = PWM_MODE,
            .channel = s_motors[i].ch,
            .timer_sel = PWM_TIMER,
            .duty = 0,
            .hpoint = 0,
            .intr_type = LEDC_INTR_DISABLE,
        };
        ESP_RETURN_ON_ERROR(ledc_channel_config(&ccfg), TAG, "ledc ch");
        ESP_LOGI(TAG, "M%d: PWM=IO%d IN1=IO%d IN2=IO%d STBY=IO%d ch%d", i,
                 s_motors[i].pwm, s_motors[i].in1, s_motors[i].in2, s_motors[i].stby, s_motors[i].ch);
    }
    ESP_LOGI(TAG, "%d motors @%dHz", MOTOR_COUNT, PWM_FREQ_HZ);
    return ESP_OK;
}

static volatile bool s_enabled;

void motors_enable(bool en)
{
    // 两片 STBY 都拉（IO51 会被写两次，无害）
    for (int i = 0; i < MOTOR_COUNT; i++) {
        gpio_set_level(s_motors[i].stby, en ? 1 : 0);
    }
    s_enabled = en;
}

bool motors_enabled(void)
{
    return s_enabled;
}

void motor_set(int idx, motor_dir_t dir, int duty)
{
    if (idx < 0 || idx >= MOTOR_COUNT) {
        return;
    }
    if (duty < 0) duty = 0;
    if (duty > MOTOR_DUTY_MAX) duty = MOTOR_DUTY_MAX;

    const motor_cfg_t *m = &s_motors[idx];
    int in1 = 0, in2 = 0;
    switch (dir) {
        case MOTOR_FORWARD: in1 = 1; in2 = 0; break;
        case MOTOR_REVERSE: in1 = 0; in2 = 1; break;
        case MOTOR_BRAKE:   in1 = 1; in2 = 1; break;
        case MOTOR_COAST:   default: in1 = 0; in2 = 0; duty = 0; break;
    }
    gpio_set_level(m->in1, in1);
    gpio_set_level(m->in2, in2);
    ledc_set_duty(PWM_MODE, m->ch, duty);
    ledc_update_duty(PWM_MODE, m->ch);
}

void motor_stop_all(void)
{
    for (int i = 0; i < MOTOR_COUNT; i++) {
        motor_set(i, MOTOR_COAST, 0);
    }
}

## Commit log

2026-06-20 backup: 工作区首版（固件骨架 + circuit-synth/KiCad 载板 + 已自动布线的 PCB）
    备份点：含用户在 KiCad 里自动布线后的 NanoSoul.kicad_pcb（1147 段+106 过孔），
    便于后续补线/改动前回退。
    [partitions.csv]
2026-06-21 pcb: 3mm 白边 + J2/J7 离 J4 + DRC 丝印告警清零
    - 最外围 3mm 白边：板放大到 94×92（Ø108 切边收小到 7/8mm），铜/器件焊盘距最外缘 ≥3mm
    （自动布线内缩 3mm；顶排 J5/J6 下移、J8 左移退出白边区）。
    - J2/J7 离 J4：右月牙整体右移 1.6mm，离 J4 本体 +0.83mm（原相擦 0.78mm）。
    - DRC = 0 warning：5 个位号(D4/D5/Q1/U1/U7)挪开、接线图例升到 0.8mm 并缩短、
    删 J3/J4 压挖孔丝印、隐藏 6 安装孔与 U7 位号。
    - 17.8mm 母座行距核对通过；4 个 M3 安装孔成规则 54×82 矩形（旧版钉在 Ø108 圆外、钻不出，已修正）。
    - 余 MOT_RTN/GND 各 1 段跨挖孔大电流网/地：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
2026-06-22 docs: 加无PCB应急方案 SKU BOM（模块清单+接线图+电气验证+电池参数）
    PCB 万一来不及打样/装配的后备方案：现成模块 + 杜邦线 + 绝缘胶带手工搭。
    含：
    - 模块级采购表（淘宝关键词+行情价，立创无成品模块故不编 LCSC C 号）+ 选购防买错提示
    - 详细接线图（graphviz 自动布局，每根箭头标引脚 IOxx→模块脚，竖版可读）
    - 电气验证：电压兼容/功率电流预算/续航/I²C 地址/GPIO 预算 + ngspice 实仿 I²C 长线上升时间
    - 电池详细参数（按整机峰值~3A 选 C 率，低 C 会压降掉电）
    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
2026-06-23 docs: 按实物模块细化应急方案接线图 + 下单前必须定清单
    收到实物模块照片，逐一核对并细化：
    - IMU 实际是 QMI8658（走 I²C，非 ICM 的 SPI）→ 图改挂 I²C1 总线(SDA/SCL/INT→IO23/ADO定址)，SPI 脚释放
    - TP4056 二合一(充电+保护)→ 省掉单独 1S 保护板；电池 B+/B−，OUT+/OUT−=VBAT
    - 加总开关(≥3A，串 OUT+) + INA219 绿端子串电机轨 + MAX17048 VLogic→3V3/Bat→电池+
    - 接线图按实物重画：电源链/双升压/I²C总线/电机/编码器，每根箭头标引脚，连接核对无误
    新增「下单前必须定」清单（一次买齐别漏）：
    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
2026-06-25 docs: 应急方案改「电脑供开发板/电池只带电机」架构，重画接线图(+共地)
    按实际决定调整供电架构：
    - 开发板改由电脑 USB 供电（独立一路，不碰电池）
    - 电池只经 XL6009 升 5.5V 带电机；电池从 TP4056 Type-C 口外部充电
    - 这套绕开了原全电池方案最大的两个风险（开发板升压扛不住 WiFi6 峰值掉电、整机~3.5A 触发 TP4056 过流跳闸）→ 不再需要 TPS61088/大 BMS
    接线图重画（graphviz，每根箭头标引脚）：
    - 两套独立电源画清；★强调 GND 必须共地(电脑地↔电池地)，否则 TB6612 信号/I²C 全失效
    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
2026-06-25 docs: 应急方案加「安全装机/上电流程」防烧件章节
    新增一节，防止装配/上电时烧任何一个零件：
    - 防烧 7 条铁律（XL6009 空载先调 5.5V 再接负载=最致命一条、断电接线、VM≠VCC、
    MAX17048 VLogic≠电池、传感器只接 3V3、上电前查短路、第一次上电手放开关）
    - 上电前万用表检查（VCC/GND/极性目检 + 电池+/3V3/5.5V 对 GND 不短路 + 共地确认）
    - 分阶段上电 5 步（调压→开发板→共地→传感器逐个I²C验→最后接电机驱动悬空小占空比试）
    - 每个件「烧的原因→怎么防」表（TB6612/开发板I²C脚/传感器/电池/XL6009/电机）
    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
2026-06-25 docs: 应急方案加「备用套装/保险包」(按风险点整理,跟主单一起下)
    就一个发货周期，按"最易烧/最易搞错/消耗快"整理备件，每件对到具体风险：
    - ① 易烧主力件直接备：TB6612×2(最易烧)、QMI8658/BH1750/INA219 各1、N20编码电机×1、XL6009×1、开关/TP4056
    - ② 主动保护小件(更难烧)：I²C 电平转换模块(救开发板I²C脚)、自恢复/玻璃管保险丝(电池短路兜底)、470/1000µF bulk电容、电阻包、肖特基
    - ③ 替代件(主件不行顶上)：DRV8833、LSM6DSO、SX1308/MT3608、杜邦线×2套、PH2.0+XH2.54端子线、热缩管
    - 提醒：开发板不可备→电平转换模块专护其I²C；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
2026-06-25 docs: 备用套装 IMU 换便宜款 MPU6050 + 保险丝给具体参数
    - IMU 替代备件 LSM6DSO(¥12) → MPU6050/GY-521(¥3~8)：便宜、ESP-IDF 例程最多；
    注明缺点(老/漂移/无硬件Tap,碰撞抬起靠固件算) + ①已备同款 QMI8658 为首选备用
    - 保险丝补具体参数表(串电池正极)：额定电流 玻璃管 T3.15A~4A 慢断 / PTC Ihold≈3A·Itrip≈6A；
    额定电压 ≥6V；分断 ≥35A；5×20mm+座；T3.15A与T4A各备3~5
2026-06-25 docs+CLAUDE: 加实物电机/编码器参数+控制，CLAUDE.md 转向无PCB ESP-IDF 编程
    实物电机到手(N20 6V/118:1/136rpm/短轴D3×8)，完善接线图与控制：
    - 电机参数表(空载40/负载90/堵转400mA·个 → 3全堵才1.2A，预算很宽松)
    - 编码器 6 线颜色接法(红白=电机±、黑蓝=编码器±、黄绿=A/B)
    - ⚠️厂商两条硬要求：① 集电极开漏 → A/B 必须加上拉(内部上拉或10k到3V3,非5V)；
    ② 电机电源≠编码器电源(电机走TB6612/5.5V、编码器走3V3,共地即可)
    - 编码器分辨率 7PPR×118=826/相 ×4=3304计数/圈 → PCNT 正交；速度/里程公式
    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
2026-06-26 docs: 编码器电机接法详解(单电机图解+方向一致性/消噪/上拉/连接器)
    - 加「单个电机怎么接」专图：N20 6 线分头接 TB6612(红白)/3V3(黑)/GND(蓝)/IO(黄绿)
    - 三个电机信号脚分配明确(M0 IO30/31、M1 IO28/29、M2 IO46/47)
    - 上拉怎么加(首选内部上拉,否则10k到3V3、长线4.7k、绝不5V)
    - 方向一致性(正PWM→计数增,反了对调黄绿;红白对调=电机反转)
    - 消噪:电机两端并 0.1µF 瓷片抑制电刷火花干扰编码器
    - 连接器以卖家线序表为准、别只认色
2026-06-26 docs: 加 TB6612 驱动板详解(澄清两个GND) + 编码器按实物丝印HH-N20-3修正
    - 新增「TB6612 详细接法」：板上引脚排布图(按丝印,GND标粉色) + 每脚接线表
    ★澄清两个GND：板上2~3个GND内部全连通=同一个地,不是逻辑地/功率地分开,
    接任一到系统共地点即可(=开发板地↔电池地的★共地)
    VM=5.5V/VCC=3V3别接反;STBY=IO52(拉低急停,两块并联);两块板汇总
    - 编码器按用户实物电机丝印 HH-N20-3 修正(之前用卖家通用图,C1/C2信号色反了)：
    白=M1/红=M2(电机)、黑=VCC/蓝=GND、绿=C1/黄=C2(信号)；单电机图同步
2026-06-26 test: 单电机桥(M2)+编码器自检固件，状态上屏
    - components/display: 复用 NanoSoul-Alpha 的 ST7701(MIPI-DSI) 点屏 93 条厂商序列
    + DPHY LDO 上电次序 + LVGL port，去掉触摸（本测试无输入）
    - drv_motor: LEDC 20kHz/10bit PWM(IO26) + IN1(IO27)/IN2(IO32)/STBY(IO52)
    - drv_encoder: PCNT ×4 正交解码(IO46/IO47，内部上拉)+到限累加防溢出
    - drv_ina219: I²C1(IO20/21) 探测 0x40，读分流电压算电流，探不到自动跳过
    - test_app: 上电自动循环正反转，屏显 动作/占空/计数/转速/方向/电流
    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
2026-06-26 test(M2自检): 修正交解码 + RPM 稳定化 + 每圈统计, STOP 改主动刹车
    - 修 PCNT B 路 level_action 应为 (KEEP,INVERSE)：之前误写 (INVERSE,KEEP)
    使 A/B 计数互相抵消，ENC 在 0/1 弹；改后正常 ×4 累加(已上板验证累计几千)
    - ENC_COUNTS_PER_REV 改 28 (7PPR×4，电机轴；商家参数页确认 7PPR 开漏)
    - RPM 改独立 100ms 周期采样 + 死区(消零飘) + EMA 平滑
    - 去掉 LVGL 的 %f（其内置 printf 默认不支持→显示 'f'）：RPM 整数、电流 mA 整数
    - 屏加 A/B 实时电平诊断行 + 每圈 F/R/N(正转/反转/净计数) 统计
    - STOP 由 coast 改 brake：每圈漂移更小、更可重复
    - UI 文案全 ASCII（消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
    [drv_encoder.c]
2026-06-30 pcb: schematic-parity 真零(零 ignore) + 重导 Gerber
    DRC `--schematic-parity --severity-all` = 0 violation / 0 unconnected /
    0 schematic-parity,62 项检查全置 error、零 ignore(旧版的 7 项 ignore 全部真修掉,
    非关检查)。verify_board 65/65、布线 778 走线+60 过孔未动。
    - 修通 circuit-synth 原理图连通性:它把一器件所有网名标签堆在 pin1 → KiCad 推断错网。
    按 .net 逐脚在真实连接点重放 global_label(fix_sch_labels),net_conflict 199→0;
    真 NC 脚在板上配同名 unconnected- 网对齐(assign_nc_nets)。
    - 板 Value 回填真实值(顺修「板上 Value=封装名」的 BOM bug)、lib_id 去库前缀(fix_board_meta);
    原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
2026-07-05 Phase 0 底座: telemetry hub + SD config + selftest 框架 + 三模式骨架
    - components/bsp: 板载固定引脚真值 (SD/I2C0/audio/DSI/CSI, 取自 testP4 实测)
    - components/telemetry: 单写多读状态快照 + esp_event 事件总线 (HUD/WS/日志共用)
    - components/storage_sd: SDSPI 挂载 (LDO_VO4) + config.json (cJSON, 缺字段用默认)
    - components/selftest: 自动循环自检框架, 串口逐项 JSON, SKIP 不算失败
    - main: Kconfig NANOSOUL_MODE (FACE/SELFTEST/TESTPANEL) + app_main 骨架 + Phase0 检查项
    - 16MB 分区表 (ota 3.1MB x2 + emote_gen/human_face_det/srmodel/storage 数据分区)
    - 三模式板外 idf.py build 全过
    [partitions.csv]
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2026-07-05 Phase B 相机 + 本地人脸检测
    - components/board_i2c0: 板载 I2C0 总线 (GPIO7/8), 相机 SCCB/编解码器/触摸共用
    - components/camera: OV5647 MIPI-CSI V4L2 采集 (移植 testP4), PPA 全幅缩放到
    检测输入帧 (300x480 保 FOV 无裁切), 回调交给 vision
    - cmake/patch_esp_video_ldo.cmake: esp_video CSI DPHY LDO 钉到共享 MIPI 轨 VO3@2500mV
    - components/vision: HumanFaceDetect (esp-dl MSRMNP s8 v1) 独立任务推理, 输出
    归一化中心偏移/面积比(距离代理)/关键点正脸度; 模型放 human_face_det 分区
    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
    [partitions.csv]
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2026-07-05 Phase D 联网 + LLM 文字链路
    - components/netlink: C6 Wi-Fi STA (esp_wifi_remote + esp_hosted over SDIO), SD
    凭据, 自动重连, SNTP + mDNS(nanosoul.local), 上报 telemetry 网络态
    - components/llm: 双协议 chat (Anthropic /v1/messages + OpenAI /v1/chat/completions),
    esp_http_client + TLS 证书 bundle, 端点/key/model 全在 SD; refusal/错误兜底
    - components/dialog: 一轮对话编排 (soul THINK -> llm -> tip 上屏 + NS_EVT_LLM_REPLY),
    语音与上位机共用
    - app_face: netlink_start + dialog_init 接入全栈
    - Phase D 自检 wifi_connect/sntp/llm_ping (无 key/离线则 SKIP, llm_ping 首次通过后锁定)
    - 板外 build 过 (3.86MB, 8% 余量 — Phase E 前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
    [app_face.c, app_selftests.c]
2026-07-05 Phase E 语音链路
    - components/audio: ES8311 全双工 I2S (录+放, esp_codec_dev), PA(IO53) 播放时使能
    - components/llm: +STT (multipart WAV -> /v1/audio/transcriptions) +TTS
    (/v1/audio/speech wav -> 重采样到 16k PCM), 端点/key 独立 SD 配置
    - components/voice: 会话编排 唤醒->LISTEN(录音 VAD 截段)->THINK(STT+chat)->
    SPEAK(TTS+播放)->回归; 半双工播时闭麦; soul 状态/表情联动
    唤醒用能量 VAD (srmodel 分区已留给 ESP-SR WakeNet 升级)
    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
    [partitions.csv]
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2026-07-05 上板 bring-up 修复: 全栈起板 + 本地感知闭环跑通 (v1.3 硅版实测)
    启动崩溃:
    - esp_hosted SDIO mempool 移到 PSRAM (ESP_HOSTED_MEMPOOL_PREFER_SPIRAM), 否则
    开机前 mempool no mem 断言循环
    - esp_netif_init 无条件早调 (无 WiFi 配置时 companion httpd 也需 tcpip 栈)
    相机 (核心本地感知):
    - 开 CONFIG_CAMERA_OV5647 (不开则 esp_video 无驱动, /dev/video0 不注册)
    - PPA 输出缓冲按 cache line(128B) 对齐, 否则 ppa_do_scale INVALID_ARG 帧全丢
    - 实测: OV5647 检测到, 采集 800x1280, 人脸检测 8fps 跑起来
    显示/HUD (屏上状态叠加):
    - HUD label 必须 gfx_obj_set_size (mask_buf=w*h, 0 尺寸 -> no mem for mask_buf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
    [app_face.c, app_selftests.c, camera.c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]
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2026-07-06 交互 M1: 运动意图仲裁器 + 修复 teleop 被 soul 覆写
    motion 组件从"最后写入者胜"改为优先级租约仲裁 (docs/12 §2):
    - 六源 REFLEX>FAULT>TELEOP>BEHAVIOR>MICRO, 每源带 deadline 租约,
    motion_request() 写槽后重仲裁; 100ms esp_timer 兜底过期回落
    - motion_arbitrate() 抽为纯函数供自检
    - motion_set_intent() 保留为 BEHAVIOR 源别名(250ms 租约), soul 调用不变
    - s_lock 扩为保护 slot+仲裁+apply 一体; drive_locked 不重入取锁避免自锁死
    修复: companion teleop 改走 TELEOP 源(ttl_ms clamp 100..2000, 缺省 300),
    soul 在 FAULT 态续租 FAULT 源 -> 遥控无法移动已故障的机器人; 租约到期
    自动回落,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
    [app_selftests.c]
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2026-07-06 交互 M7: 运动原语库 + FACE 模式传感喂数
    新增 soul_prim 原语播放器 (docs/12 §5, 纯逻辑可测):
    - nudge/retreat_shy/wiggle/tilt_glance/scan/spin, 时间参数化 (vx,vy,wz) 曲线,
    100ms 缓入缓出 + 调用方注入的幅度 scale (活层折入 ±15% jitter, 测试传 1.0)
    - soul_task 原语层: 原语活跃时经 MOTION_SRC_BEHAVIOR 覆写状态机意图, beh 遥测
    随原语名更新
    soul 行为接原语:
    - GAZED -> retreat_shy (S5); 敲击 -> nudge (二次敲击 2×幅度); SPEAK -> wiggle (S12);
    丢脸转 IDLE -> scan 找人 + 咦?人呢 (S6)
    - soul_eval APPROACH 改比例控制: |cx|>0.15 先转正再平移, 速度随距离误差 (S4)
    - S9 被拨轮: "o"+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
    [app_face.c, app_selftests.c, app_sense.c]
2026-07-06 交互 M8: 自主行为 + 堵转保护 + 微动作 + 收尾
    soul 自主与微动作 (docs/12 S11/S3):
    - S11 自主行为: IDLE 超 autonomy_idle_s 后按能量泊松间隔(45s..300s)自发
    scan/spin/打盹自语; **硬约束零位移**(无悬崖传感器不盲移)
    - S3 微动作: 静止且非勿扰时经 MOTION_SRC_MICRO 叠加呼吸式轻摆(最低优先级)
    - PERM_SILENT(开会)全停微动作与自主
    堵转过流保护 (docs/12 S14, app_sense):
    - 纯逻辑 stall FSM (stall_step: 判据持续->TRIP->3s后RETRY->max_retry->GIVEUP),
    供 stall_sim 自检
    - 接入 sense_task (仅 motion_enabled 时): 高流+驱动硬+不转 -> motors_enable(false)
    + FAULT + STALL 事件; 自动试探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
    [app_selftests.c, app_sense.c]
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2026-07-06 测试 T3: 补 i2c1_scan / ina219_read / encoder_pulse 自检项
    - i2c1_scan: 探 0x6A/0x23/0x40 三从机齐则 PASS，MAX17048(0x36) 作信息位
    - ina219_read: 电流读数在 ±3.2A 合理域；不在线 SKIP
    - encoder_pulse(MANUAL): 被动读三路计数 + A/B 电平（主动驱动验证交上位机
    motor_test 面板，那里会先摘 motion apply 回调避免抢电机）
    (hwinfo 帧 + sense 流已在 T2 随 testlink 落地。)
    板外 idf.py build 通过。
    [app_selftests.c]
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2026-07-06 测试 T4 修复: app_face.h 自包含 stdint.h
    app_face_motor_apply(const int16_t[]) 声明用了 int16_t，但头只含 stdbool.h，
    且 app_face.c 在 stdint.h 之前先 include 本头 → 全新构建时 'unknown type name
    int16_t'。头文件应自包含依赖类型。(T4 首建的 | tail 管道掩盖了 idf.py 退出码，
    漏检；已改用显式 exit code 校验。)
    idf.py build 退出码 0，nanosoul.bin 链接通过。
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2026-07-08 音频: ES8311 全双工修复 (8-bit I2C 地址 0x30) + 提示音
    esp_codec_dev 的 audio_codec_i2c_cfg_t.addr 要 8-bit 移位地址(内部 >>1),
    原来传 7-bit 0x18 实际访问总线上不存在的 0x0C,寄存器读写全 NAK,喇叭麦克风
    一起哑。改传 ES8311_CODEC_DEFAULT_ADDR(0x30)。
    - 恢复全双工: TX+RX 单口, WORK_MODE_BOTH, dev_type IN_OUT, set_in_gain(30dB)
    - play_notes() 抽出 chime 音序器; 新增 audio_fail_tone() 两下行音失败提示
    - audio_play 加墙钟日志(诊断写路径丢数据)
    - 音量按 config 设置
    [audio.c]
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2026-07-08 构建/esp_hosted 配置: SDIO 三坑修复 + WS 缓冲 + TEST 覆盖层
    - ESP_HOSTED_MEMPOOL_PREFER_SPIRAM=n: SDIO 缓冲放 PSRAM 与 DSI/XIP 抢带宽致
    DMA/cache 一致性错 → 整板重启(版本读成 0.0.0/len 0x666 都是它的假象);
    OOM 改用 SDIO_TX/RX_Q_SIZE 20→10 解决
    - WS_BUFFER_SIZE=4096: 火山 openspeech 握手响应头 >1KB, 默认 1024 报
    "Header size exceeded buffer size"(此值只能 Kconfig 改)
    - sdkconfig.test: 无跳线强制 TEST 模式的覆盖层, 固化进仓库(此前指向临时目录)
    - .gitignore: 忽略真凭证 config.json 与 clangd 缓存
2026-07-08 测试模式/上位机: inject wake 触发真实对话 + 诊断收尾
    - proto.c: inject_event{name:"wake"} 除发事件外加调 voice_trigger(),
    上位机注入 wake = 真实跑一轮 录音→ASR→chat→TTS→播放; testlink 加 voice 依赖
    - companion.c: WS token 做 url_decode(允许非 ASCII token)
    - camera.c: OV5647 SCCB 探测门, 探不到即跳过 CSI 初始化(优雅降级)
    - app_testmode.c: 删除已死的 probe_i2c0_audio 诊断(音频问题已修复归档到 skill)
    - docs/13: 补 wake 注入语义
    [app_testmode.c, camera.c, proto.c]
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2026-07-08 docs: 00 基线同步到 2026-07-08 语音链现状
    - 语音链从「mic FAIL 待查」更新为「实板全链打通」(seed-asr WSS + plan
    chat + 全双工 + 预卷 + 静默丢弃误唤醒)
    - 唤醒词记为「小王小王」(文本门近期 / MultiNet 远期)
    - 会话流水线段落更新(8s/静音阈/失败兜底)
2026-07-08 资产: 火山语音协议 PDF + yun 表情 + 外壳设计初稿
    - docs 火山方舟 PDF ×2: seed-asr/tts 协议真值源(volc_asr.c 分帧照此实现)
    - spiffs_image/yun.bin: 晕表情素材(待接入 face 映射)
    - enclosure/: 史莱姆外壳 cadquery 模型初稿(基于旧板框,待按 62×72 重对齐)
    [preview.scad]
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2026-07-08 测试: 电机 bring-up 扫描工具(编译开关,默认关)
    NS_MOTOR_BRINGUP=1 时,TEST 模式 boot 后一次性扫每轮 fwd/rev(45% 500ms),
    日志打编码器 Δcount + RPM，用于方向/接线校准。自包含(自己 init 电机+编码器)、
    在 app_face_run 之前启动，故对 flaky LCD/触摸排线导致的启动挂起免疫。
    实测:M0/M1/M2 三轮双向 OK、编码器计数正常(电源不稳修复后)。
    [app_testmode.c]
2026-07-08 视觉认主: 端侧人脸识别闭环 (检测→识别→表情/问候, 全本地推理)
    - vendor human_face_recognition 0.3.2 (esp-dl@f43b41f): 注册表归档钉
    human_face_detect ~0.4.1 与锁定的 0.5.0 无解; 附 VENDORED.md 记录来源
    与上游多脸 max_element 反向 bug (调用方只传单脸规避)
    - MFN 特征模型 (1.27MB) 走 SD 卡加载 (CONFIG..._SDCARD_DIR="model/p4",
    就现役卡既有目录), app 体积零增长; 缺模型时优雅降级只关识别
    - 特征库 /sdcard/nanosoul/face.db 持久化, 实测重启后 db:4 faces 恢复
    - 相机旋转支持: PPA SRM 硬件旋转, vision.rotate 配置 (0/90/180/270),
    实测模组横装 270° 后画面转正 (真人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
    [app_face.c, camera.c, proto.c]
2026-07-08 底盘: 轮速闭环 + 里程计 + 校准链路 (前馈+PI, 默认回开环)
    - app_wheelctrl: 每轮前馈(ks/kv) + 官方 pid_ctrl 的 PI 修正, 设定点死区防抖
    - motion/odom: 按电机轴编码器计数积分里程位姿 (docs/14 口径)
    - ns_config: motion.calib (closed_loop / ks·kv / PID / 轮径·体半径 / rpm_max),
    closed_loop=false 一键回开环; JSON overlay 支持 calib.pid 与 ks/kv 三元数组
    - testlink: wheel_sp / pid_set / odom_reset 校准协议命令 + telemetry wheel/odom 通道
    - app_face: 按 closed_loop 决定 motion apply 桥 (闭环 wheel_ctrl_apply / 开环裸占空比);
    开环下 wheelctrl 也起, 只测速+里程计不驱动
    - selftest: FK 往返 + o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
    [app_face.c, app_selftests.c, app_testmode.c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]
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2026-07-08 chore: 修正 .gitignore 锁文件规则 — 行尾注释使 .~lock.*# 失效
    gitignore 不支持行尾注释, 注释挪到独立行, 规则方能生效。
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2026-07-09 外壳: 切到 SolidWorks 2024 手绘模型 (models/ SW 源 + STL/3mf 导出)
    - enclosure/models/: 8 个 .SLDPRT + 装配体.SLDASM 手绘源，stls/ 存可打印导出
    - 移除被取代的旧 cadquery enclosure/README.md 与 esp32p4wifi6_dimensions.jpg
    - README 工作区结构行标注外壳改用 solidworks 2024 重新手绘
    [ScreenShell.SLDPRT, boardsupporter.SLDPRT, boardsupporter.STL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]
2026-07-09 整理: 清掉 main 上旧 cadquery 外壳残留，统一到 SolidWorks
    - 删 enclosure/model/*.py(.scad)、DESIGN.md(史莱姆/cadquery 口径)、DIMENSIONS.md
    - README 外壳节改指 enclosure/models/(SLDPRT/SLDASM) + stls/ 导出，去掉指向已删文件的死链
    - enclosure/ 自此只留 SolidWorks 手绘一套
    [preview.scad]
2026-07-09 docs: 对齐 mic_record 自检状态 — 07-05 那条 FAIL 已被 07-08 语音链收尾消解
    07-05 bring-up 快照的唯一 FAIL(mic_record/ES8311 ADC 静音)在 2026-07-08
    语音链上板收尾(ec3af47: seed-asr WSS + plan chat/tts)时打通:mic 录音正常、
    说话→ASR→云 LLM→TTS→出声全链实测、对话可演示。README + docs/00 §现状/§下一步
    同步标注已消解、自检计数待重跑刷新。代码本身(components/llm/volc_asr.c 等)已在 main。
2026-07-23 pcb: 70×90mm 4层载板终态入库 — 176/176布通 DRC/ERC/verify全绿 + fab包重导 + USB-C朝向修正
    - 重绘 62×72 → 70×90（对齐 7×9cm 洞洞板实物形态，手焊友好间距：无源栅格 3.0、摆位净空 0.8、连接器 keepout 1.2）
    - 修复 62×72 定稿携带的 USB-C 机械 bug：TYPE-C-31-M-12 rot270 开口朝板内插不进线 → rot90 悬出右板边 1.6mm
    - 中槽恢复需求全长 15.5×59（62×72 缩 50 是小板妥协）
    - fab/ 全量重导（Gerber/钻孔/CPL/BOM），料号沿用嘉立创 SMT 核对版
    - 文档同步：docs/05 §0 终态、docs/00 §1.2/§5-B/§6、README PCB 段（消除「fab 包待重导」过时表述）
    - .vscode：恢复被插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
2026-07-23 语音: 设备端唤醒落地 — MultiNet「小王小王」默认 + WakeNet 喵伴/能量 VAD 编译期回退 + 唤醒提示音 + 主动续听
    - voice 组件 AFE 化：ESP-SR v2.4.7（P4 崩溃修复版）AFE 单麦(aec/se/ns 关, WebRTC VAD mode3) 进 voice_task 主循环；
    MN 引擎=mn7_cn 常驻识别运行时拼音命令 "xiao wang xiao wang"（官方模型零训练，四音节抗误触）；
    WN 引擎=wn9_nihaomiaoban_tts2（设备端唤醒即应答，绕过文本门）；VAD 保留为无模型兜底
    - 应答后 follow_window_s 主动续听：SR 引擎下保住「免唤醒词续聊」，三引擎行为统一
    - 唤醒提示音：A5→E6 纯五度双音软包络铃（~340ms），Cha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
    [partitions.csv]
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
